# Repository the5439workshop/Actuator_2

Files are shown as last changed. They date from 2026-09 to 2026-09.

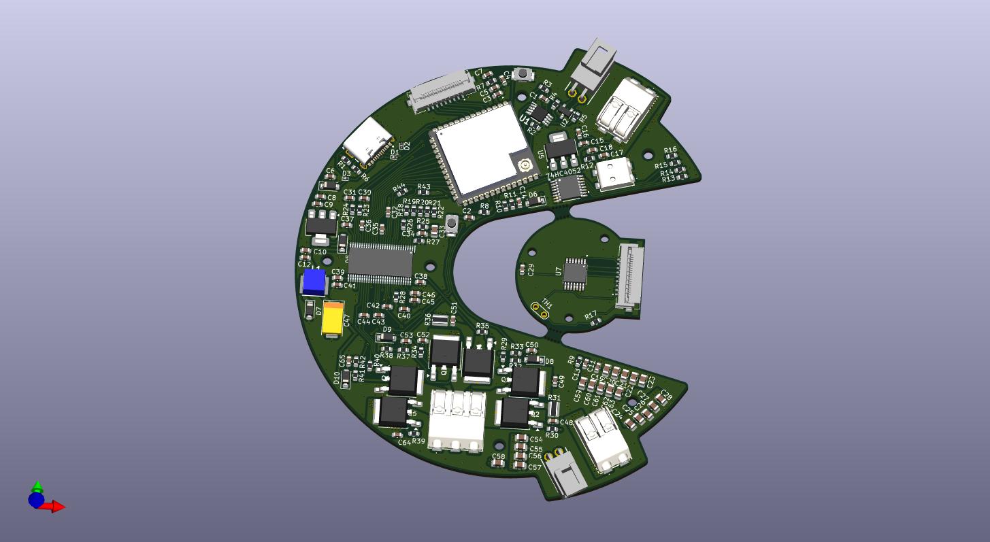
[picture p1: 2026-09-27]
PCB/motor_driver_3d.jpg

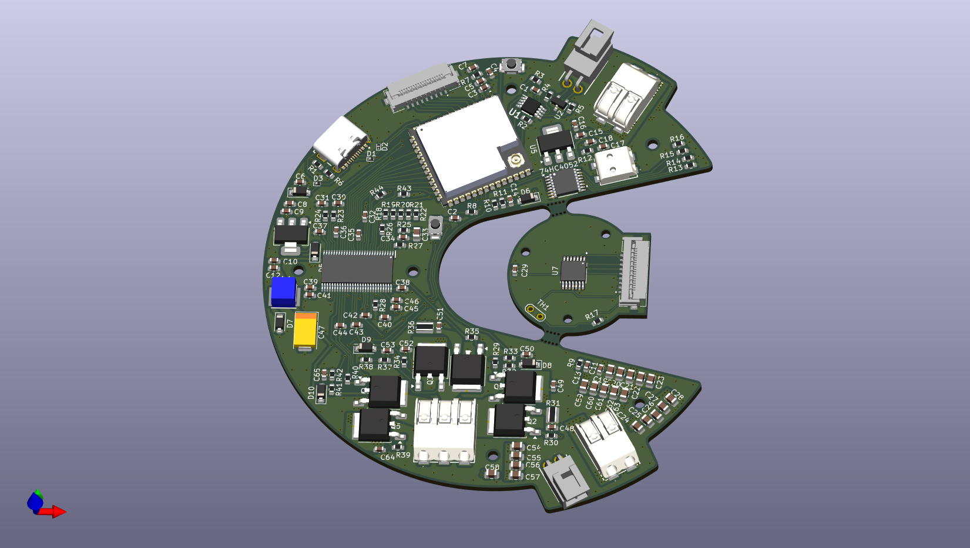
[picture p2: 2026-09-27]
PCB/motor_driver.png

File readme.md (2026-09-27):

Here are the files for the acuator, I was planing to release them sooner, but things got in the way. These are as is and not very well documented. You will need to adjust tolerances if you try to manifacture them as it will be specific to how well you CNC cuts. I cut the gears from 7075 aluminium, which is typically not a great material for gears, but I dont have the tools to cut steal so it is what it is. The rest is in 6061 alu or 3d printed in petg. It works, but dont expect longevity comparible to what you can buy. Economically, you are better of buying actuators, learning wise you are better of designing your own. So, not sure who this is for. I will update the files, once I have gotten further with the project. For me it is about designing and manifacturing all the core components, becaouse that's how I enjoy learning. These acutators are not designed for any water or dusty enviorments, the cooling system, will bring all particles through the actuator. Ideally, you want the stator on the outside for cooling, but I don't want to hand wire 10 of those stators, so compromises have been made. 

This is not a guide for how to build them, just the collection of the files. At somepoint I might make a guide... 

There are 5 types bearings:

 * 55x45x6 mm
 * 44x35x5 mm
 * 21x15x4 mm
 * 12x8x3.5 mm
 * 8x4x3 mm x6


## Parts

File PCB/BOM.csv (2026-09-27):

Reference | Value | Footprint | Qty | DNP | MANUFACTURER | MANUFACTURER_PART_NUMBER | Description | Distributor Link
C1,C2,C5,C7,C9,C11,C12,C14,C16,C18,C42,C43,C44,C45,C50,C53 | 0.1uF | Capacitor_SMD:C_0603_1608Metric | 16 |  | Murata Electronics | GCG188R91H104KA01D | Capacitor 0.1 uF >35V | https://www.mouser.se/ProductDetail/Murata-Electronics/GCG188R91H104KA01D?qs=mKZLDXqphFiFhPDl%252BfeUIg%3D%3D
C3,C6,C8,C10,C15,C17 | 10 uF | Capacitor_SMD:C_0603_1608Metric | 6 |  | Murata Electronics | GRM188R6YA106MA73J | Capacitor 10uF >35V | https://www.mouser.se/ProductDetail/Murata-Electronics/GRM188R6YA106MA73J?qs=5aG0NVq1C4xLSwNPdfnaYg%3D%3D
C4,C36,C37 | 1 uF | Capacitor_SMD:C_0603_1608Metric | 3 |  | TAIYO YUDEN | UMK107AB7105KA-T | Capacitor 1uF >35V | https://www.mouser.se/ProductDetail/TAIYO-YUDEN/UMK107AB7105KA-T?qs=%252BAZVS4b%2FkgKLk%2FvFAZMoRQ%3D%3D
C13 | 0.01 uF | Capacitor_SMD:C_0603_1608Metric | 1 |  | Murata Electronics | GCM188R71H103KA37J | Capacitor 0.01uF >35V | https://www.mouser.se/ProductDetail/Murata-Electronics/GCM188R71H103KA37J?qs=N3Kl9KD794T3%2FxlXdF0Axg%3D%3D
C19,C20,C21,C22,C23,C24,C25,C26,C27,C28,C54,C55,C56,C57,C58,C59,C60,C61,C62,C63 | 22 uf | Capacitor_SMD:C_0805_2012Metric | 20 |  | TDK | C2012X5R1V226M125AC | Capacitor 22uF >35V | https://www.mouser.se/ProductDetail/TDK/C2012X5R1V226M125AC?qs=6JAMGB%252BEdkyUk0d2Mu2IrQ%3D%3D
C29,C39,C40,C65 | 0.1 uF | Capacitor_SMD:C_0603_1608Metric | 4 |  | Murata Electronics | GCG188R91H104KA01D | Capacitor 0.1 uF >35V | https://www.mouser.se/ProductDetail/Murata-Electronics/GCG188R91H104KA01D?qs=mKZLDXqphFiFhPDl%252BfeUIg%3D%3D
C30,C31,C32,C49,C52,C64 | 2.2 uF | Capacitor_SMD:C_0603_1608Metric | 6 |  | Murata Electronics | GRM188R61H225KE11D | Capacitor 2.2uF >35V | https://www.mouser.se/ProductDetail/Murata-Electronics/GRM188R61H225KE11D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
C33 | 6.8 uF | Capacitor_SMD:C_0805_2012Metric | 1 |  | TDK | C2012X5R1V685K125AC | Capacitor 6.8uF >35V | https://www.mouser.se/ProductDetail/TDK/C2012X5R1V685K125AC?qs=6JAMGB%252BEdkx%252BaHR67HUtEg%3D%3D
C34 | 120 pF | Capacitor_SMD:C_0603_1608Metric | 1 |  | Vishay / Vitramon | VJ0603D121KXBAJ | Capacitor 120pF >35V | https://www.mouser.se/ProductDetail/Vishay-Vitramon/VJ0603D121KXBAJ?qs=f%252BL2SN1GfctWhDNaXZI1mg%3D%3D
C35 | 22 pF | Capacitor_SMD:C_0603_1608Metric | 1 |  | Samsung Electro-Mechanics | CL10C220JB8NNWC | Capacitor 22pF >35V | https://www.mouser.se/ProductDetail/Samsung-Electro-Mechanics/CL10C220JB8NNWC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
C38 | 15 pF | Capacitor_SMD:C_0603_1608Metric | 1 |  | Murata Electronics | GCM1885C1H150JA16J | Capacitor 15pF >35V | https://www.mouser.se/ProductDetail/Murata-Electronics/GCM1885C1H150JA16J?qs=N3Kl9KD794RiYSVQCGj%252BdA%3D%3D
C41,C46 | 4.7 uF | Capacitor_SMD:C_0603_1608Metric | 2 |  | TDK | C1608X5R1V475K080AC | Capacitor 4.7uF >35V | https://www.mouser.se/ProductDetail/TDK/C1608X5R1V475K080AC?qs=dfay7wIA1uF9DVjUL4K4oA%3D%3D
C47 | 47 uF | Capacitor_Tantalum_SMD:CP_EIA-7343-15_Kemet-W | 1 |  | Panasonic | 35TQS47MEX | Polarized capacitor 47 uF >35V | https://www.mouser.se/ProductDetail/Panasonic/35TQS47MEX
C48,C51 | 1 nF | Capacitor_SMD:C_0603_1608Metric | 2 |  | Murata Electronics | GCM1885C2A102FA16D | Capacitor 1 nF >35V | https://www.mouser.se/ProductDetail/Murata-Electronics/GCM1885C2A102FA16D?qs=QzBtWTOodeWZsFfmRZw1Bg%3D%3D
D1,D2,D3 | ESD9B3.3ST5G | Diode_SMD:D_SOD-923 | 3 |  | onsemi | ESD9B3.3ST5G | ESD | https://www.mouser.se/ProductDetail/onsemi/ESD9B3.3ST5G?qs=yU2N9dt%252BrfmXrPf3vhgUEA%3D%3D
D4,D5,D6,D7,D8,D9,D10 | D_Schottky_3.3v | Diode_SMD:D_SOD-123 | 7 |  | Diodes Incorporated | 1N5819HW-7-F | Schottky diode | https://www.mouser.se/ProductDetail/Diodes-Incorporated/1N5819HW-7-F?qs=NQ47qNm99eDyWTEd07miYA%3D%3D
IC1 | DRV8302DCAR | component_footprints:SOP50P810X120-57N | 1 |  | Texas Instruments | DRV8302DCAR | 3-Phase Brushless Motor Pre-Driver with Dual Current Sense Amps and Buck Converter (PWM Ctrl) | https://www.mouser.se/ProductDetail/Texas-Instruments/DRV8302DCAR?qs=UMk2QrKu%2FwyEhbV7PXJXLQ%3D%3D
J1,J2 | 2060-452_998-404 | component_footprints:2060452998404 | 2 |  | WAGO Corporation | 2060-452/998-404 | SMD PCB terminal block; push-button; 0.75 mm; Pin spacing 4 mm; 2-pole; Push-in CAGE CLAMP; in tape-and-reel packaging | https://www.digikey.se/en/products/detail/wago-corporation/2060-452-998-404/15540283
J3,J4 | 105313-1202 | component_footprints:1053131202 | 2 |  | Molex | 105313-1202 | Molex Electronics, Series Number 105313, 2.5mm Pitch 2 Way 1 Row Right Angle PCB Header, Solder Termination, 6.5A | https://www.mouser.se/ProductDetail/Molex/105313-1202?qs=PqFvFmEiOr6Yr1uRJ10a3A%3D%3D
J5 | USB4215-03-A_REVA | component_footprints:GCT_USB4215-03-A_REVA | 1 |  | Global Connector Technology | USB4215-03-A | USB-C (USB TYPE-C) USB 2.0 Receptacle Connector 24 (16+8 Dummy) Position Surface Mount, Right Angle; Through Hole | https://www.mouser.se/ProductDetail/GCT/USB4215-03-A?qs=IKkN%2F947nfBipec8wvDabA%3D%3D
J6 | 2059-302_998-403 | component_footprints:2059302998403 | 1 |  | WAGO Corporation | 2059-302/998-403 | Fan connector | https://www.digikey.se/sv/products/detail/wago-corporation/2059-302-998-403/15532751
J7,J8 | 200528-0090 | component_footprints:200528-0090 | 2 |  | Molex | 200528-0090 | Molex Easy-On 200528 Series 1mm Pitch 9 Way Right Angle SMT Male FPC Connector, ZIF Bottom Contact | https://www.mouser.se/ProductDetail/Molex/200528-0090?qs=IvjI65BR3TXhl6Ou0vwBHg%3D%3D
J9 | 2060-453_998-404 | component_footprints:2060453998404 | 1 |  | WAGO Corporation | 2060-453/998-404 | Motor | https://www.digikey.se/sv/products/detail/wago-corporation/2060-453-998-404/15581970
L1 | 22 uH | component_footprints:NRS5040T220MMGK | 1 |  | TAIYO YUDEN | NRS5040T220MMGK | Inductor | https://www.mouser.se/ProductDetail/TAIYO-YUDEN/NRS5040T220MMGK?qs=y6ZabgHbY%252BwHM2WsXBuQTw%3D%3D
Q1,Q2,Q3,Q4,Q5,Q6 | RFD16N05LSM9A | Package_TO_SOT_SMD:TO-252-2 | 6 |  | onsemi / Fairchild | RFD16N05LSM9A | MOSFET | https://www.mouser.se/ProductDetail/onsemi-Fairchild/RFD16N05LSM9A?qs=nAte8rcNofLNLDEc74GIWA%3D%3D
R1,R6 | 5.1 k | Resistor_SMD:R_0603_1608Metric | 2 |  | YAGEO | RT0603BRD075K1L | Resistor | https://www.mouser.se/ProductDetail/YAGEO/RT0603BRD075K1L?qs=aZCcseWLxnua40%252BM84F3mA%3D%3D
R2,R3,R7,R8,R17,R18,R19,R20,R22,R43,R44 | 10 k | Resistor_SMD:R_0603_1608Metric | 11 |  | Vishay / Beyschlag | MCT0603MD1002DP500 | Resistor | https://www.mouser.se/ProductDetail/Vishay-Beyschlag/MCT0603MD1002DP500?qs=oBjDkOCjPF1CUAoPD7yTwg%3D%3D
R4,R5 | 10 thick film | Resistor_SMD:R_0603_1608Metric | 2 |  | Vishay | CRCW060310R0FKEBC | Resistor | https://www.mouser.se/ProductDetail/Vishay/CRCW060310R0FKEBC?qs=wd5RIQLrsJj1Wo77dZVziA%3D%3D
R9 | 3.3 k | Resistor_SMD:R_0603_1608Metric | 1 |  | YAGEO | RT0603FRE133K3L | Resistor | https://www.mouser.se/ProductDetail/YAGEO/RT0603FRE133K3L?qs=1mbolxNpo8c7XaNIiBx7KQ%3D%3D
R10,R32,R37,R41 | 69.8 k | Resistor_SMD:R_0603_1608Metric | 4 |  | Panasonic | ERA-3AEB6982V | Resistor | https://www.mouser.se/ProductDetail/Panasonic/ERA-3AEB6982V?qs=nuXzIS8loXG44F6SvdF0rQ%3D%3D
R11,R33,R38,R42 | 4.99 k | Resistor_SMD:R_0603_1608Metric | 4 |  | Vishay / Beyschlag | MCT0603MD4991DP500 | Resistor | https://www.mouser.se/ProductDetail/Vishay-Beyschlag/MCT0603MD4991DP500?qs=EzBFWPtgsb3WU6Es1nZy2w%3D%3D
R12 | 240 | Resistor_SMD:R_0603_1608Metric | 1 |  | Vishay / Beyschlag | MCT06030C2400FP500 | Resistor | https://www.mouser.se/ProductDetail/Vishay-Beyschlag/MCT06030C2400FP500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
R13 | 1350 | Resistor_SMD:R_0603_1608Metric | 1 |  | YAGEO | RT0603BRD071K35L | Resistor | https://www.mouser.se/ProductDetail/YAGEO/RT0603BRD071K35L?qs=bQfrgN9vNvzfnncXb1XZ4g%3D%3D
R14 | 422 | Resistor_SMD:R_0603_1608Metric | 1 |  | YAGEO | RT0603FRE07422RL | Resistor | https://www.mouser.se/ProductDetail/YAGEO/RT0603FRE07422RL?qs=4CyHz7GXqSil%2FA183G1h5g%3D%3D
R15 | 655 (657) | Resistor_SMD:R_0603_1608Metric | 1 |  | KOA Speer | RN73H1JTTD6570D100 | Resistor | https://www.mouser.se/ProductDetail/KOA-Speer/RN73H1JTTD6570D100?qs=Tw8F%252BABiY2omz5bCYgquwA%3D%3D
R16 | 1 k | Resistor_SMD:R_0603_1608Metric | 1 |  | Vishay / Beyschlag | MCT06030C1001FP500 | Resistor | https://www.mouser.se/ProductDetail/Vishay-Beyschlag/MCT06030C1001FP500?qs=7ZE6F4QMOBbsjeUdqW8cwA%3D%3D
R21 | 31.6 k | Resistor_SMD:R_0603_1608Metric | 1 |  | Vishay / Beyschlag | MCT06030C3162FP500 | Resistor | https://www.mouser.se/ProductDetail/Vishay-Beyschlag/MCT06030C3162FP500?qs=wTZ%2FFzl837YBtpLxOjdP0Q%3D%3D
R23,R24 | 56 | Resistor_SMD:R_0603_1608Metric | 2 |  | Panasonic | ERA-3AEB560V | Resistor | https://www.mouser.se/ProductDetail/Panasonic/ERA-3AEB560V?qs=nho8PGNfA6pLPdv4OomYKQ%3D%3D
R25 | 16.2 k | Resistor_SMD:R_0603_1608Metric | 1 |  | Vishay / Beyschlag | MCT06030C1622FP500 | Resistor | https://www.mouser.se/ProductDetail/Vishay-Beyschlag/MCT06030C1622FP500?qs=wTZ%2FFzl837askLTeC7YJGg%3D%3D
R26 | 1 | Resistor_SMD:R_0603_1608Metric | 1 |  | Vishay / Beyschlag | MCT06030C1008FP500 | Resistor | https://www.mouser.se/ProductDetail/Vishay-Beyschlag/MCT06030C1008FP500?qs=sIxod1zg5hFmg%2F6YexVHSg%3D%3D
R27 | 205 k | Resistor_SMD:R_0603_1608Metric | 1 |  | YAGEO | RT0603FRE07205KL | Resistor | https://www.mouser.se/ProductDetail/YAGEO/RT0603FRE07205KL?qs=4CyHz7GXqSizcEQ6BDWqXg%3D%3D
R28 | 1 M | Resistor_SMD:R_0603_1608Metric | 1 |  | Vishay / Beyschlag | MCT06030C1004FP500 | Resistor | https://www.mouser.se/ProductDetail/Vishay-Beyschlag/MCT06030C1004FP500?qs=7ZE6F4QMOBYb3%252B6kTBjugg%3D%3D
R29,R30,R34,R35,R39,R40 | 10 | Resistor_SMD:R_0603_1608Metric | 6 |  | Vishay / Beyschlag | MCT06030C1009FP500 | Resistor | https://www.mouser.se/ProductDetail/Vishay-Beyschlag/MCT06030C1009FP500?qs=4DXlcry4fcXzntE6aB0o9Q%3D%3D
R31,R36 | 10 m | Resistor_SMD:R_0612_1632Metric | 2 |  | Panasonic | ERJ-D2DFR010V | Resistor | https://www.mouser.se/ProductDetail/Panasonic/ERJ-D2DFR010V?qs=3HJ2avRr9PLPJn6aLNO%252BHA%3D%3D
SW1,SW2 | SW_Push | component_footprints:SKRKAGE020 | 2 |  | Alps Alpine | SKRKAGE020 | Push button switch, generic, two pins | https://www.mouser.se/ProductDetail/Alps-Alpine/SKRKAGE020?qs=EU6FO9ffTwdVPz%2Fcqm4gTQ%3D%3D
TH1 | Thermistor_NTC | TestPoint:TestPoint_2Pads_Pitch2.54mm_Drill0.8mm | 1 | DNP | Murata Electronics | NXFT15XH103FEAB030 | Temperature dependent resistor, negative temperature coefficient | https://www.mouser.se/ProductDetail/Murata-Electronics/NXFT15XH103FEAB030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
U1 | ~ | component_footprints:SN65HVD75DGKR | 1 |  | Texas Instruments | SN65HVD75DGKR | Rs485 | https://www.mouser.se/ProductDetail/Texas-Instruments/SN65HVD75DGKR?qs=E2%2FxqS9xjzrac0D8q%2FrjAA%3D%3D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
U2 | ~ | Package_TO_SOT_SMD:SOT-23 | 1 |  | Littelfuse | SP712-02HTG | TVS Diodes | https://www.mouser.se/ProductDetail/Littelfuse/SP712-02HTG?qs=GBLSl2AkiruqudcLsbr7vw%3D%3D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
U3 | ESP32-S3-WROOM-1U-N8R2 | component_footprints:XCVR_ESP32-S3-WROOM-1U-N8R2 | 1 |  | Espressif Systems | ESP32-S3-WROOM-1U-N8R2 | ESP32-S3-WROOM-1U-N8R2 | https://www.mouser.se/ProductDetail/Espressif-Systems/ESP32-S3-WROOM-1U-N8R2
U4 | AMS1117-3.3 | Package_TO_SOT_SMD:SOT-223-3_TabPin2 | 1 |  | UMW | AMS1117-3.3 | LDO 3.3V | https://www.digikey.se/sv/products/detail/umw/AMS1117-3-3/17635254
U5 | LM317_SOT-223 | Package_TO_SOT_SMD:SOT-223-3_TabPin2 | 1 |  | Texas Instruments | LM317DCYR | 1.5A 35V Adjustable Linear Regulator, SOT-223 | https://www.mouser.se/ProductDetail/Texas-Instruments/LM317DCYR?qs=YhsVCygOPE0H9jB5Yaa05Q%3D%3D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
U6 | 74HC4052PW_118 | component_footprints:TSSOP16_5P1X4P5_NEX | 1 |  | Nexperia | 74HC4052PW,118 | IC multiplexer | https://www.mouser.se/ProductDetail/Nexperia/74HC4052PW118?qs=P62ublwmbi%2Fhh72g3HnbZg%3D%3D
U7 | AS5047P-ATSM | component_footprints:SOP65P640X120-14N | 1 |  | ams OSRAM | AS5047P-ATSM | Position sensor | https://www.mouser.se/ProductDetail/ams-OSRAM/AS5047P-ATSM?qs=cGEy3R83DS8fzNOVLHtOgg%3D%3D

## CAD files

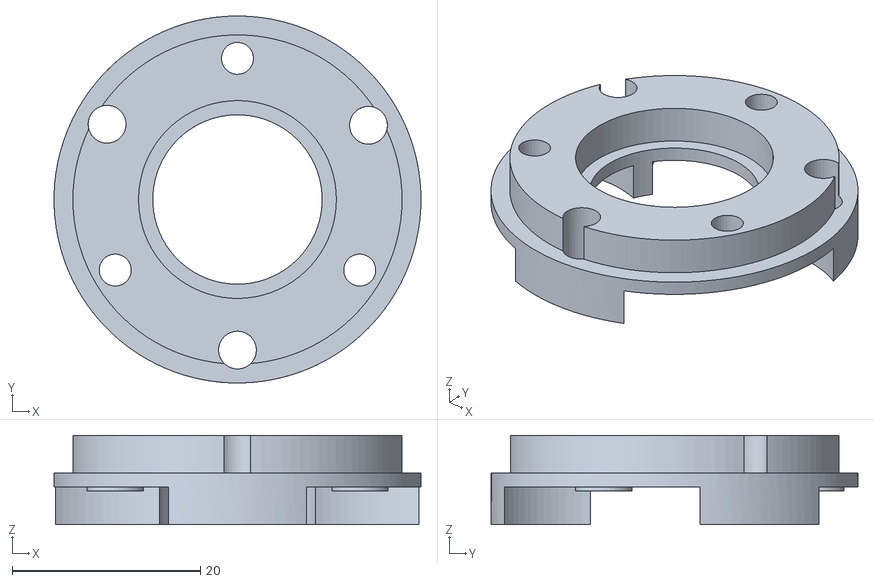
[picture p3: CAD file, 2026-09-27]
actuator_v2_stl/carrier_4_alu.stl
39.0 x 39.0 x 9.50

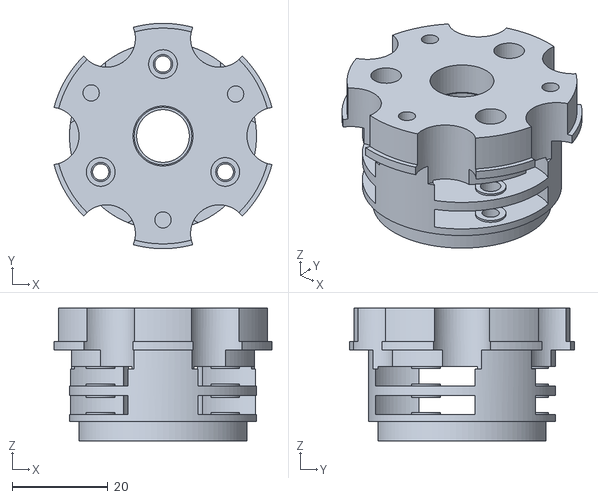
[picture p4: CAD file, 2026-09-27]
actuator_v2_stl/carrier_alu.stl
45.5 x 47.0 x 27.7

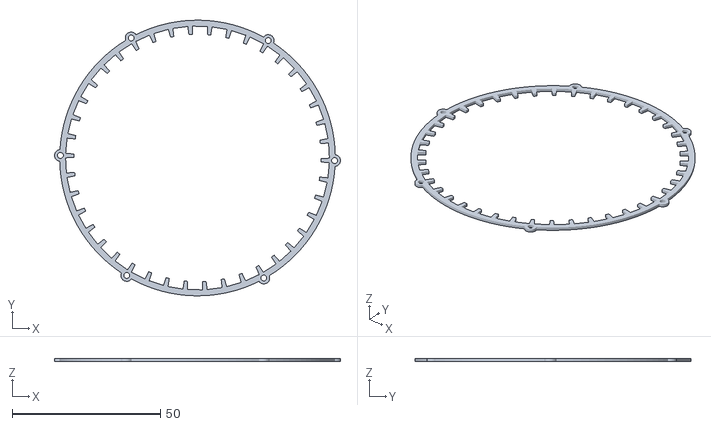
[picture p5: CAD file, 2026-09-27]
actuator_v2_stl/magnet_ring_steel.stl
96.5 x 93.0 x 1.00

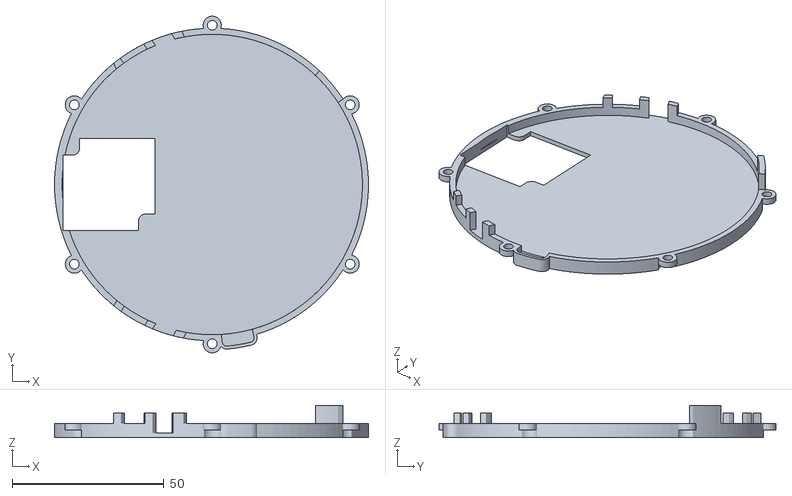
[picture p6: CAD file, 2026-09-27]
actuator_v2_stl/bottom_petg.stl
103.5 x 111.0 x 10.6

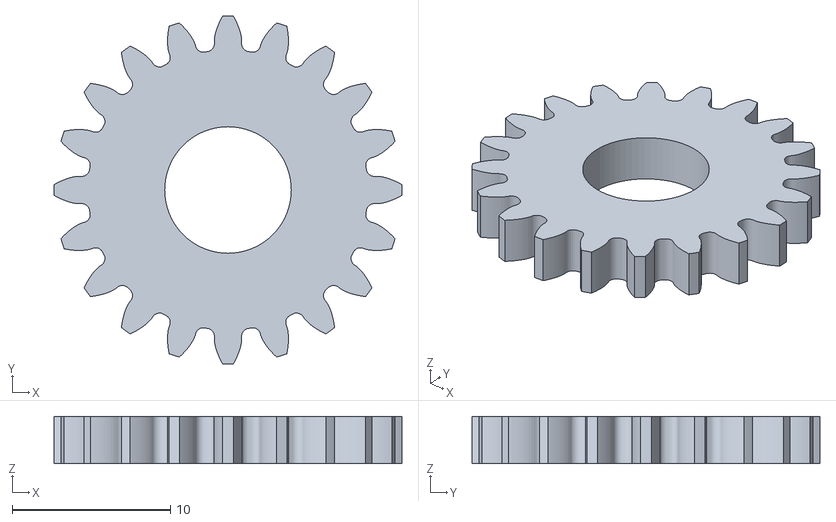
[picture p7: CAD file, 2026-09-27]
actuator_v2_stl/planet_gear.stl
22.0 x 22.0 x 3.00

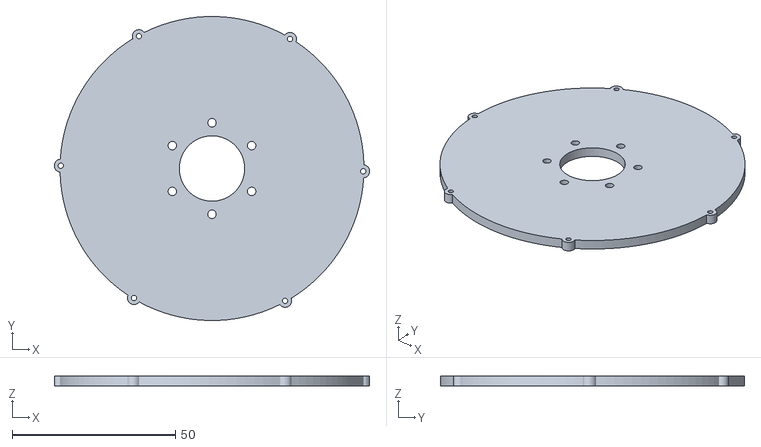
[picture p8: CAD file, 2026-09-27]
actuator_v2_stl/rotor_plate_alu.stl
96.5 x 93.0 x 3.00

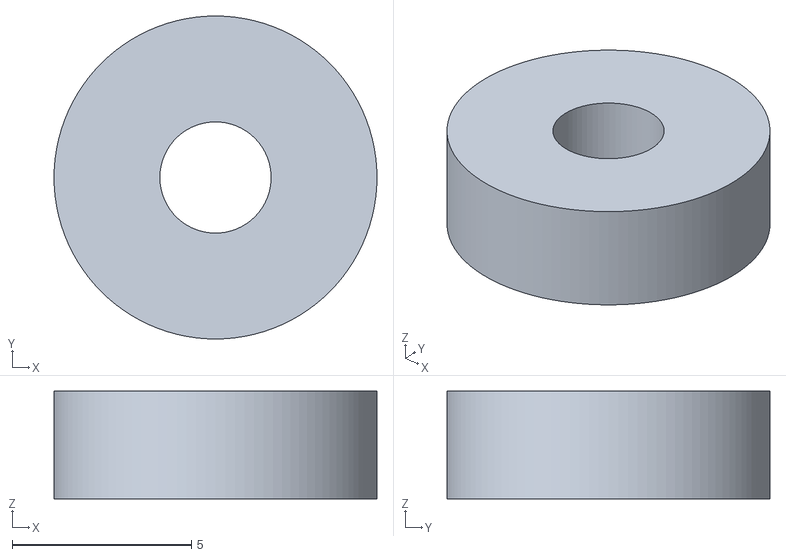
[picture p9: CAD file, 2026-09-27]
actuator_v2_stl/rotor_holder_pteg.stl
9.00 x 9.00 x 3.00

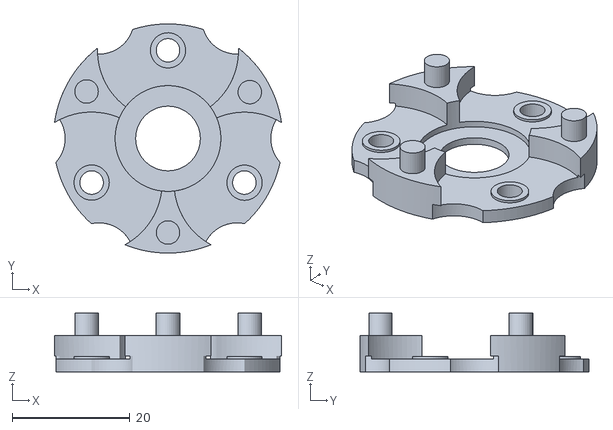
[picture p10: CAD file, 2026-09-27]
actuator_v2_stl/carrier_2_alu.stl
38.6 x 39.0 x 10.0

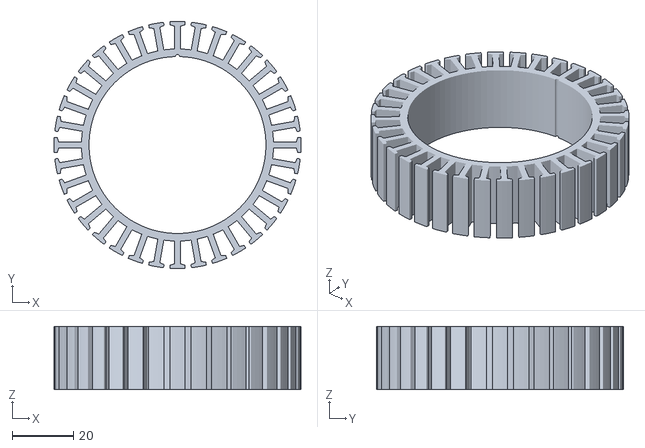
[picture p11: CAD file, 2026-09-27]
actuator_v2_stl/stator_mockup.stl
81.0 x 81.0 x 20.7

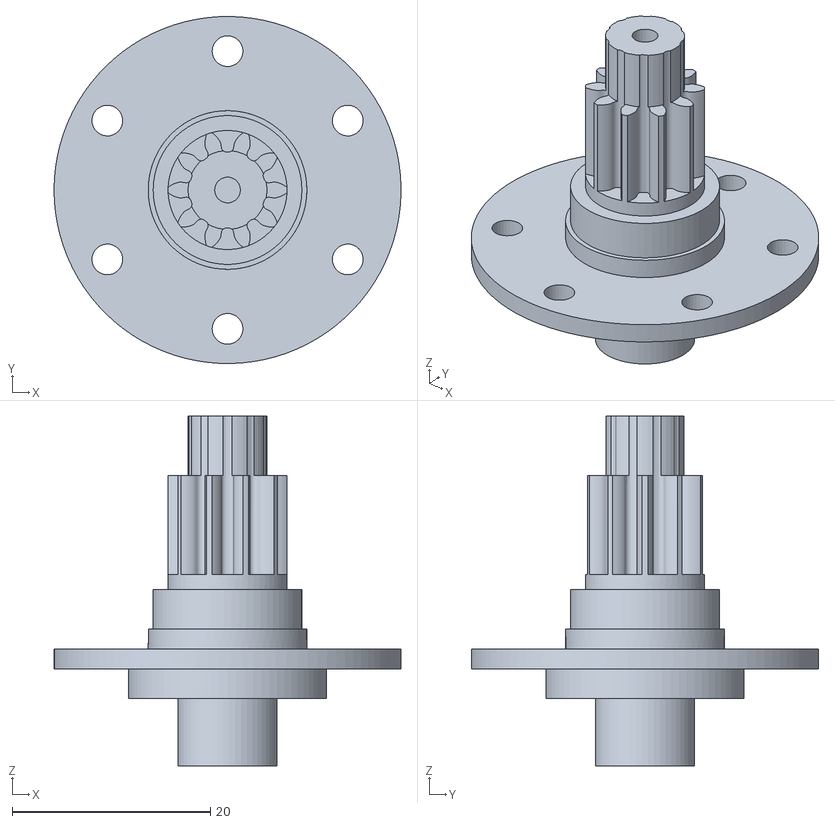
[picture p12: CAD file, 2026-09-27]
actuator_v2_stl/sun_gear.stl
35.0 x 35.0 x 35.3

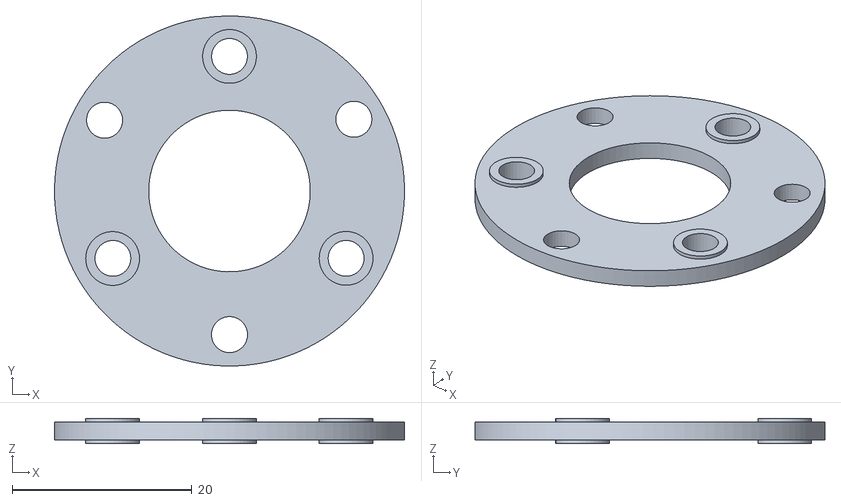
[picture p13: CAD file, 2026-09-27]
actuator_v2_stl/carrier_3_alu.stl
39.0 x 39.0 x 2.80

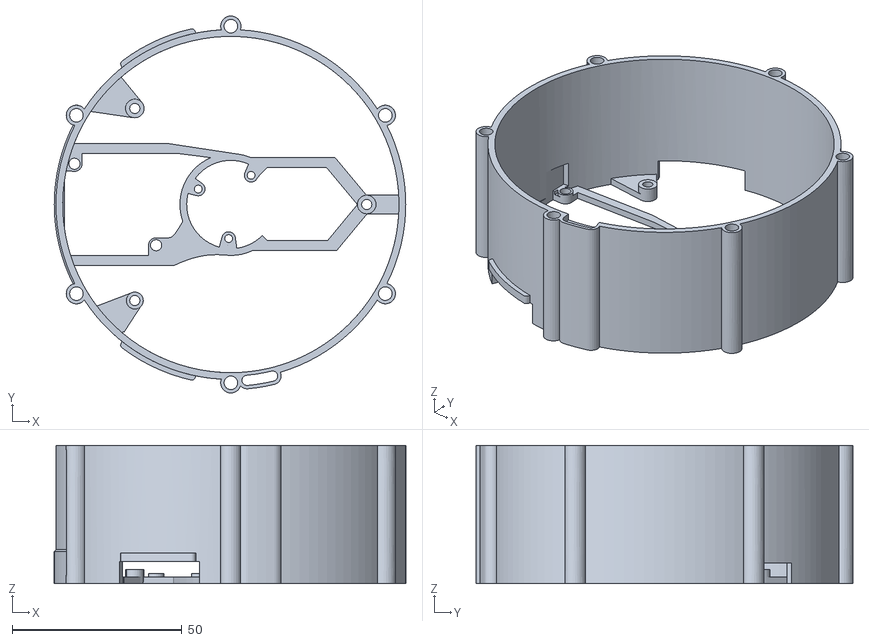
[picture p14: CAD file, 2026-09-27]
actuator_v2_stl/outer_petg.stl
103.5 x 111.0 x 40.7

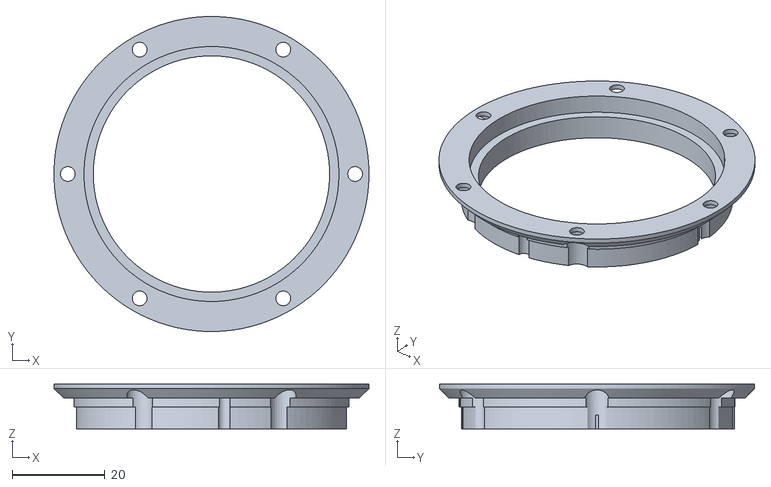
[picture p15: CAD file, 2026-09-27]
actuator_v2_stl/stator_adapter_alu.stl
68.0 x 68.0 x 9.70

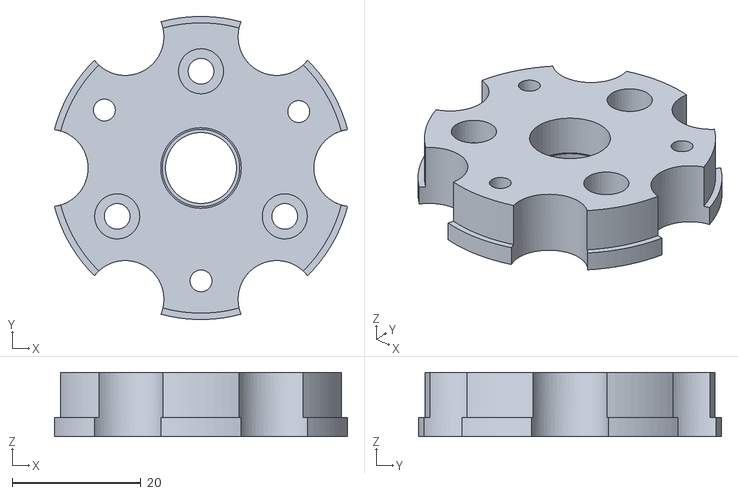
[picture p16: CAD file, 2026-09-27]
actuator_v2_stl/carrier_1_alu.stl
45.5 x 47.0 x 10.0

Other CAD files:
actuator_v2_stl/ring_gear.stl
actuator_v2_stl/ring_gear_spacer_alu.stl
actuator_v2_stl/stator_mount_bottom_alu.stl
actuator_v2_stl/top_alu.stl

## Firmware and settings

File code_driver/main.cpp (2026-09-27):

/**
 * ESP32 position motion control example with magnetic sensor
 */
#include <SimpleFOC.h>
#include <TemperatureSensor.h>

// SPI Magnetic sensor instance (AS5047U example)

int CS_ = 7;
int MISO_  = 5;
int MOSI_ = 6;
int SCK_ = 15;

#define RS485_DIR_PIN 1

// magnetic sensor instance - SPI

MagneticSensorSPI sensor = MagneticSensorSPI(AS5047_SPI, CS_, MISO_, MOSI_, SCK_);


float beta = 3434.0; float t0_c = 25.0;  float r0 = 10000.0; float r_fixed = 10000.0; float v_in = 3.3;
int pin_ntc = 4;

TemperatureSensor temp_sensor = TemperatureSensor(beta, t0_c, r0, r_fixed,  v_in);

#define INH_A 14 //gpio D10
#define INH_B 12 //gpio D9
#define INH_C 10 //gpio D8
#define INL_A 13  //gpio A3
#define INL_B 11 //gpio A6
#define INL_C 9 //gpio A5

#define EN_GATE 21 // GPIO 21
#define M_PWM 35 //

// Motor instance
BLDCMotor motor = BLDCMotor(21, 3.0);
BLDCDriver6PWM driver = BLDCDriver6PWM(INH_A, INL_A, INH_B, INL_B, INH_C, INL_C, EN_GATE);

#define SO1_fan 2
#define SO2_fan 42

// angle set point variable
//float target_angle = 0;
// instantiate the commander
Commander command = Commander(Serial);
//void doTarget(char* cmd) { command.scalar(&target_angle, cmd); }

void setup() {
  
  // use monitoring with serial 
  Serial.begin(115200); // For USB C

  //Serial1.begin(115200, SERIAL_8N1, 44, 43); // RX=44, TX=43 for RS485 
  _delay(2000);
  SimpleFOCDebug::enable(&Serial);
  pinMode(RS485_DIR_PIN, OUTPUT);
  digitalWrite(RS485_DIR_PIN, LOW);  // Receive mode initially
  // enable more verbose output for debugging
  // comment out if not needed
  //SimpleFOCDebug::enable(&Serial);

  // initialise magnetic sensor hardware
  sensor.init();
  analogReadResolution(12);
  pinMode(M_PWM, OUTPUT);
  digitalWrite(M_PWM, LOW);

  pinMode(SO1_fan, OUTPUT);
  pinMode(SO2_fan, OUTPUT);
  digitalWrite(SO1_fan, LOW);
  digitalWrite(SO2_fan, LOW);
  
  // link the motor to the sensor
  motor.linkSensor(&sensor);

  // driver config
  // power supply voltage [V]
  driver.voltage_power_supply = 20;
  driver.pwm_frequency = 20000;

  driver.init();
  // link the motor and the driver
  motor.linkDriver(&driver);

  motor.voltage_sensor_align = 5.0;

  motor.foc_modulation = FOCModulationType::SpaceVectorPWM;
  //motor.foc_modulation = FOCModulationType::SinePWM;

  // set motion control loop to be used
  motor.controller = MotionControlType::velocity_openloop;

  motor.torque_controller = TorqueControlType::voltage;
  motor.controller = MotionControlType::torque;

// Limits 
  motor.velocity_limit = 1.0; 
  motor.current_limit = 40;   

  // initialize motor
  motor.init();
  // align encoder and start FOC
  //motor.zero_electric_angle  = 1.0071; // rad
  //motor.sensor_direction = Direction::CW; // CW or CCW

  motor.initFOC();


  Serial.println("Sensor zero offset is:");
  Serial.println(motor.zero_electric_angle, 4);
  Serial.println("Sensor natural direction is: ");
  Serial.println(motor.sensor_direction == Direction::CW ? "Direction::CW" : "Direction::CCW");

  motor.target = 0.0; //initial target velocity 1 rad/s
  
  Serial.println(F("Motor ready."));
  Serial.println(F("Set the target angle using serial terminal:"));
  _delay(1000);
}


bool readSerial1(char* msg, int& msg_cnt){
  
  try{
    while (Serial.available()) 
    {
      // get the new byte:
      char ch = Serial.read();
      // end of user input
      if (ch == '\n') {
        return 1;
      }
      msg[msg_cnt] = ch;
      msg_cnt += 1;
      if (msg_cnt >20){
        msg_cnt = 0;
        return 1;
      }
    }
  }
  catch (...){
  }


  return 0;
}


int i_ = 0;

const int max_input_lenght = 20;
char received_chars[max_input_lenght+3] = {0}; //!< so far received user message - waiting for newline
int rec_cnt = 0; //!< number of characters receives
//String msg = "";
int msg_length = 0;

int int_tansmit = 1;

unsigned long previousMicros = micros();    // Stores the last time loop ran
unsigned long currentMicros = micros();    // Stores the last time loop ran

float angle_s = 0.0;

float temp_s = 0.0;
float result__ = 0.0;
int why;

void loop() {

  // main FOC algorithm function
  // the faster you run this function the better
  // Arduino UNO loop  ~1kHz
  // Bluepill loop ~10kHz
  //motor.loopFOC();

  // Motion control function
  // velocity, position or voltage (defined in motor.controller)
  // this function can be run at much lower frequency than loopFOC() function
  // You can also use motor.move() and set the motor.target in the code
  //motor.move(target_angle);
  motor.loopFOC();
  
  
  // function intended to be used with serial plotter to monitor motor variables
  // significantly slowing the execution down!!!!
  // motor.monitor();


  if (int_tansmit == 0){
    
    if (readSerial1(received_chars, rec_cnt)){
      int_tansmit = 1;
      if (received_chars[0] == 'T'){
        // Create a buffer to hold the substring
        char substring[rec_cnt] = {0}; // +1 for the null terminator
        //memset(substring, 0, rec_cnt); // Ensure it's null-terminated
        // Copy the characters from received_chars to substring
        for (int i = 0; i < rec_cnt-1; i++) {
          substring[i] = received_chars[1 + i];
        }
        try{
        float result = atof(substring); 
        result__ = result;
        motor.target = result;
        
        }catch(...){
          why = 1;
        }
      } 
      
      
     rec_cnt = 0;
    }
  }
  if (rec_cnt >= max_input_lenght){
    rec_cnt = 0;
  }

  
  if (int_tansmit == 1) {
    angle_s = sensor.getAngle();
    int adcValue = analogRead(pin_ntc);
    float v_termistor = adcValue * (3.33 / 4095.0);
    temp_s = temp_sensor.readTemp(v_termistor); 
    digitalWrite(RS485_DIR_PIN, HIGH); // Transmit mode
    int_tansmit = 2;
    previousMicros = micros();
  }

  currentMicros = micros();
  if (int_tansmit == 2){
    if (currentMicros - previousMicros >= 100){
      Serial.print(temp_s);
      Serial.print(",");
      Serial.println(angle_s);
      Serial.flush();
      int_tansmit = 3;
      digitalWrite(RS485_DIR_PIN, LOW);  // Back to receive mode
      previousMicros = micros();
    }
  }

  currentMicros = micros();
  if (int_tansmit == 3){
    if (currentMicros - previousMicros >= 10){
      int_tansmit = 0;
      digitalWrite(RS485_DIR_PIN, LOW);  // Back to receive mode
    }
  }

  


  motor.move();

  // user communication
  //command.run();
}
